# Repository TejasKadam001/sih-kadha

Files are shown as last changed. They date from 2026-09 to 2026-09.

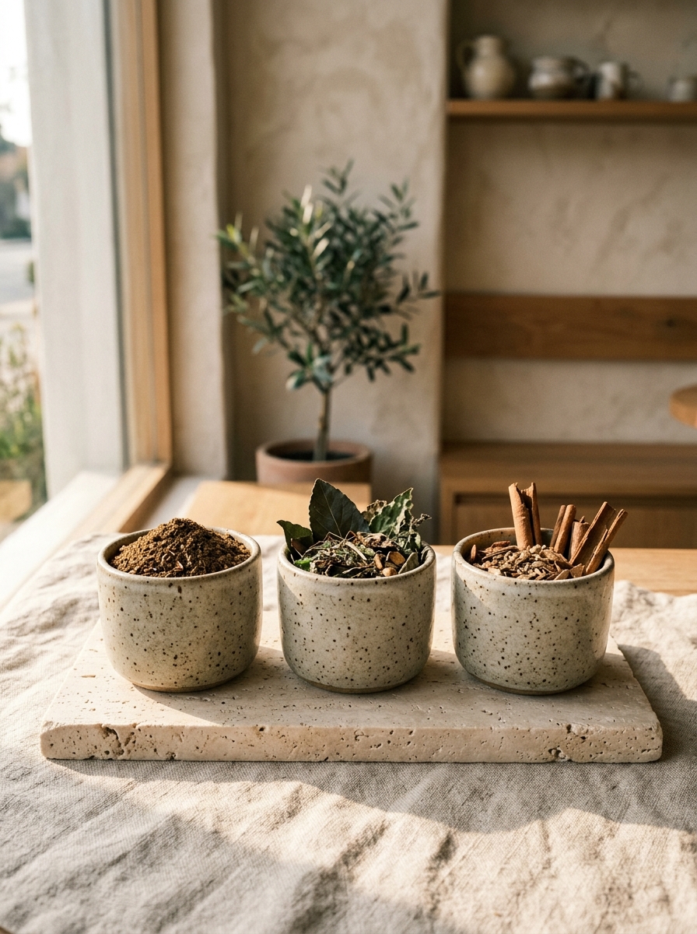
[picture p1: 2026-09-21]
website/assets/pods_tray.jpg

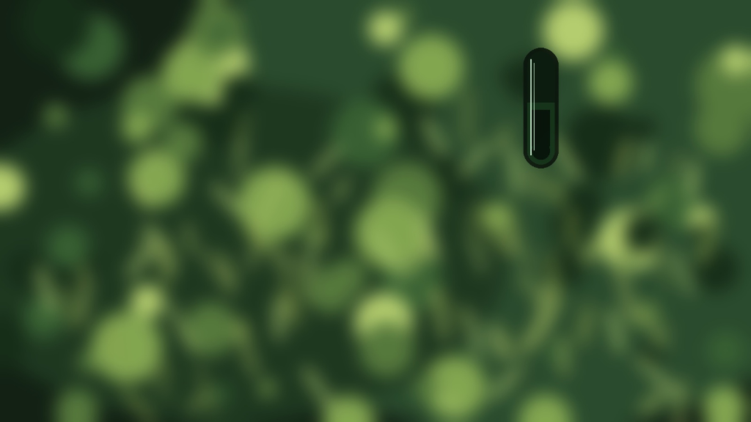
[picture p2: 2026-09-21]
app/assets/science_macro.jpg

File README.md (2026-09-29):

# iKwath: Smart Pod-Based Ayurvedic Decoction Appliance

**SIH26048: iKwath, a pod-based smart Kwatha (Kadha) maker that prepares a fresh, AFI/API-standardized decoction from coarse powder (yavakuta churna) on demand, in the shortest practical time, without altering the decoction's quality or yield**
Ministry of Ayush / All India Institute of Ayurveda (AIIA) | Smart India Hackathon 2026
**Team:** MACH 2
**Design philosophy:** Classical Fidelity | Hardware-Enforced Safety | Measured Endpoints, Not Timers | Honest Project Status








---

## 1. Problem Statement Context (SIH26048)

Kwatha (also Kashaya or Kadha) is the primary aqueous decoction in Ayurveda. Coarse herbal powder (yavakuta churna) is boiled in a specified multiple of water and reduced, classically to one quarter of the volume, then filtered immediately.

The difficulty is that a classical Kwatha has no preservatives and stays therapeutically useful for only a few hours. Making it properly means 45 to 60 minutes of monitored simmering, so patients and OPD clinics often switch to bottled, industrially preserved syrups that suffer thermal degradation or inconsistent yield.

* **Long manual process:** open-pot evaporation needs constant attention for close to an hour.
* **Temperature ceiling:** classical practice prescribes gentle heat (Manda Agni). At or above 100 C volatile terpenes and thermolabile glycosides degrade.
* **Standardization gap:** hand preparation varies in water ratio, reduction and filtration, so dose consistency is poor.
* **No traceability:** there is no record of what was brewed, from which batch, at what concentration.

---

## 2. Integrated Solution Overview

**iKwath** is a countertop, single-dose extraction appliance built around five ideas:

1. **Pod-based dosing:** a single-use pod holds 25 to 35 g of certified coarse powder and doubles as the filter (150 to 250 micron mesh). An NTAG213 NFC tag on the rim carries the formulation profile.
2. **Vacuum-assisted evaporation:** the sealed SS304 chamber runs at 0.5 to 0.6 atm so water boils at about 82 to 86 C. The liquid boils vigorously while staying inside the 85 to 90 C envelope.
3. **Measured endpoint:** a load cell tracks the mass of the chamber and ends the boil when 300 g (+/- 2 g) has evaporated, an exact 4:1 reduction of 400 mL. The endpoint is a measurement, not a timer.
4. **Three independent hardware safety layers:** fuse, lid interlock and bimetallic thermal cutoff, all working with the firmware switched off.
5. **Companion app and cloud model:** live brew dashboard, pod profile catalogue, dose log and clinic fleet view (see the status note in section 8).

> Scientific and engineering classification: iKwath is a prototype design for a standardized decoction appliance. It is not a certified medical device, and this repository does not contain laboratory validation of extract quality. See section 10 for what is and is not built.

---

## 3. Extraction Physics

The Ayurvedic Formulary of India (AFI) and Ayurvedic Pharmacopoeia of India (API) set water ratio by herb hardness:

| Herb class | Parts | Water ratio (w/w) | Reduction | Concentration |
|---|---|---|---|---|
| Soft (Mridu): leaves, flowers | 16 | 16 | to 1/4 | about 4x |
| Medium (Madhyama): bark, stems | 8 | 8 | to 1/4 | about 2x |
| Hard (Kathina): roots, heartwood | 4 | 4 | to 1/4 | about 1x |

The working profile is 400 mL of water reduced to a 100 mL dose.

Cycle time falls from 45 to 60 minutes to 9 to 12 minutes without raising liquid temperature, using four levers:

```mermaid
graph TD
    A[Classical bottleneck] --> B[Open pot at 98-100 C]
    B --> C[Slow evaporation: 45-60 min]
    B --> D[Thermal loss of volatile actives]

    E[iKwath approach] --> F[Sealed chamber at 0.5-0.6 atm]
    F --> G[Boils at 82-86 C, Manda Agni preserved]
    E --> H[Wide shallow pan: about 3x surface area]
    E --> I[Recirculation over the pod bed]
    E --> J[Forced vapor exhaust]

    G --> K[Active cycle target: 9-12 min]
    H --> K
    I --> K
    J --> K
```

Particle size follows PCIM&H specification AFI/2020/KC/1.0: 100 percent through IS sieve 22 (710 micron) and not more than 10 percent through sieve 44 (355 micron). Details: [docs/pod-and-extraction.md](docs/pod-and-extraction.md).

---

## 4. Machine Working Principle

```mermaid
stateDiagram-v2
    [*] --> Idle: Powered on
    Idle --> PodDetect: Pod inserted, lid latched
    PodDetect --> WaterFill: NFC profile validated
    WaterFill --> PreSoak: 400 mL metered by load cell
    PreSoak --> ActiveBoil: 180 s soak finished

    state ActiveBoil {
        [*] --> PressureRamp: Vacuum pump on
        PressureRamp --> PIDHold: 0.5-0.6 atm reached
        PIDHold --> PIDHold: Temperature held 85-88 C
        PIDHold --> MassCheck: Recirculation running
        MassCheck --> [*]: 300 g evaporated
    }

    ActiveBoil --> Dispense: Vent chamber, run dispense pump
    Dispense --> Eject: about 100 mL delivered
    Eject --> Idle: Pod dropped to bin
```

Eight steps: interlocked pod loading, metered water intake, pre-soak, controlled vacuum boil, recirculation with vapor stripping, mass-reduction endpoint, filtered dispense at 55 to 60 C, automatic pod ejection. Step-by-step detail: [docs/control-sequence.md](docs/control-sequence.md).

---

## 5. Repository Layout

```
SIH/
├── README.md                      Main specification and status
├── INSTALL.md                     How to open, run and rebuild each part
├── CHANGELOG.md                   Versioned release notes
├── PUSH_LOG.md                    What each push to the repository did
├── SIH26048_PROJECT_REPORT.md     Full technical submission report
├── ps_shortlist.md                Problem-statement shortlist and selection notes
├── app/                           Product landing site (single page, with media assets)
│   ├── index.html
│   ├── styles.css
│   ├── assets/                    Product, pod and lifestyle imagery, hero video
│   └── _assets_backup/            Unused media with a restore script
├── website/                       Interactive brew-simulator web app (HTML, CSS, JS)
│   ├── index.html
│   ├── styles.css
│   ├── app.js                     Screen state machine, extraction simulator, greetings
│   ├── manifest.json
│   └── assets/
├── pcb/                           Committed KiCad project (control and power circuitry)
│   ├── ikwath.kicad_sch
│   ├── ikwath.kicad_pcb
│   └── ikwath.kicad_pro
├── ino/                           ESP32 firmware (Arduino sketch)
│   └── ikwath_firmware/
│       ├── ikwath_firmware.ino    State machine, sensors, safety checks, serial and optional HTTP
│       ├── pins.h  config.h       Pin map and tunable settings
│       ├── pid.h  hx711_lite.h    Heater PID and load-cell reader
│       └── profile.h              Pod tag payload format
├── models/                        Process model notebook: vacuum boiling, energy budget, endpoint noise, pod tag
│   └── ikwath_process_model.ipynb
├── docs/                          Engineering documentation derived from this repository
│   ├── pod-and-extraction.md
│   ├── control-sequence.md
│   ├── pinout-and-buses.md
│   ├── safety-system.md
│   ├── pcb-status.md
│   ├── bom.md
│   ├── app-and-cloud.md
│   ├── limitations.md
│   ├── judge-qna.md
│   └── README.md
├── blehpcb/                       Local PCB generation work (gitignored)
│   ├── BOM.csv
│   ├── generate_final_kicad8.py
│   ├── ikwath-control-board/  ikwath-power-board/
│   ├── *-drc.rpt  *-erc.rpt       KiCad rule-check reports
│   └── pcbreal/                   Scripted placement, routing and stackup iterations
└── blehread/                      Local research dossiers (gitignored)
    ├── research.md  structure.md  pcb.md  app_and_website.md  names.md  open.md
```

The two gitignored folders are working material that lives only on the author's machine; see [PUSH_LOG.md](PUSH_LOG.md) for what is actually pushed.

---

## 6. Dual-PCB Hardware Architecture

The electronics are split into two boards so that sensitive analog measurement is isolated from inductive relay switching.

```mermaid
flowchart LR
    subgraph PB["Power Board"]
        AC["220V AC"] --> PS1["12V 5A AC-DC supply"]
        PS1 --> F1["5A DC fuse"]
        F1 --> V12["12V bus"]
        V12 --> BUCK["LM2596 buck to 5V"]
        V12 --> RLY["Relays 1-7: heater, vacuum pump, recirculation pump, dispense pump, inlet valve, lid lock, exhaust fan"]
    end

    subgraph CB["Control Board"]
        MCU["ESP32 DevKit V1"]
        MCU --> DS["DS18B20 liquid temperature"]
        MCU --> HX["HX711 + load cell"]
        MCU --> NFC["MFRC522 NFC reader"]
        MCU --> I2C["I2C bus"]
        I2C --> OLED["SSD1306 OLED"]
        I2C --> BMP["BMP280 pressure"]
        I2C --> PCF["PCF8574 x2: relays, LEDs"]
        MCU --> TDS["Analog TDS sensor"]
        MCU --> SW["Limit switches: lid, boil-over, level"]
        MCU --> SRV["SG90 pod ejector"]
    end

    BUCK -->|5V| MCU
    PB <-->|"Ribbon: power, I2C, PID, signals"| CB
```

| Board | Target size | Notes |
|---|---|---|
| Control | 70 x 60 mm in the specification (generated variants are larger, see [docs/pcb-status.md](docs/pcb-status.md)) | 2-layer, dedicated analog ground zone, 4x M3 |
| Power | 80 x 70 mm in the specification | 2-layer, heavy power traces, opto-isolated relay drive, 4x M3 |

Pin map and I2C addresses: [docs/pinout-and-buses.md](docs/pinout-and-buses.md).

---

## 7. Three-Tier Hardware Safety System

These layers act independently of firmware:

1. **Bimetallic thermal cutoff (95 to 100 C)**, in contact with the boiler wall and in series between Relay 1 and the heater. If the chamber overheats for any reason, including a welded relay, it opens the circuit.
2. **Mechanical lid interlock**, wired in series with the heater's 12 V feed. Opening the lid cuts heater power in hardware.
3. **5 A fast-acting fuse** on the 12 V rail against short circuits and pump stall.

The firmware in `ino/` adds supervisory checks on top (boil-over sensor, water level, enclosure NTC, over-temperature, timeouts); it is a first draft that has not yet run on the appliance (section 10). Details: [docs/safety-system.md](docs/safety-system.md).

---

## 8. Companion Applications

Two web front ends are in the repository. Both run with no build step and no dependencies.

| Folder | What it is |
|---|---|
| `website/` | Interactive mobile-style app: logo intro, login, time-based greeting, pod dropdown (Triphala, Ayush, Dashamoola), five-stage extraction simulator with live countdown, temperature dial, 400 to 100 mL gauge and a PID curve pinned to the 85 to 90 C band, notification bell, pod scanner viewfinder, profile view, Android frame toggle |
| `app/` | Single-page product site: appliance, pods, app, formulations, science and standards sections, sign-in and sign-up modals, product photography and hero video |

**Status:** the extraction screen is a simulator driven by `website/app.js`. It does not connect to a device. The BLE provisioning, local WebSocket, MQTT telemetry and cloud database described in [docs/app-and-cloud.md](docs/app-and-cloud.md) are the intended architecture, not running code.

---

## 9. Bill of Materials

`blehpcb/BOM.csv` lists 46 line items (ESP32, sensors, NFC reader, display, expanders, 7 relays, pumps, valves, heater, servo, fan, safety parts, passives and connectors). The file's own total row, and the sum of its cost column, is **INR 4,588** (about US$55), reading each figure as a line total. If those were unit prices the bill would be INR 8,335, so spot-check a few lines against supplier listings before quoting a cost. Full table and notes: [docs/bom.md](docs/bom.md).

---

## 10. Project Status: Built Versus Designed

| Area | Status |
|---|---|
| Problem analysis, extraction physics, pod design | Written (`blehread/research.md`, `docs/pod-and-extraction.md`) |
| Pin-by-pin hardware specification | Written (`blehread/pcb.md`, `docs/pinout-and-buses.md`) |
| KiCad schematic and PCB | Present in several iterations; `pcb/` is the committed one. Rule-check results vary by iteration, and copper routing is incomplete in some (see [docs/pcb-status.md](docs/pcb-status.md)) |
| Web front ends | Built and runnable; extraction is simulated |
| ESP32 firmware | Written (`ino/`): full cycle, safety checks, serial and optional HTTP interface. Not yet compiled here or run on hardware |
| Physical prototype and lab validation | **Not done** (no measured extract quality, no measured cycle time) |
| Mobile app, cloud backend, MQTT | **Design only** |

The 9 to 12 minute cycle, the 85 to 90 C envelope and the 300 g endpoint are design targets derived from the physics, not measured results. An energy balance in `models/ikwath_process_model.ipynb` shows that the cycle time is set by heater power: the 50 W element in the current bill of materials is far too small for a 12 minute cycle, so the heater is an open design decision. [docs/limitations.md](docs/limitations.md) lists what is needed to turn each into a measured claim.

---

## 11. Documentation Map

| Document | Contents |
|---|---|
| [SIH26048_PROJECT_REPORT.md](SIH26048_PROJECT_REPORT.md) | Full technical submission report |
| [INSTALL.md](INSTALL.md) | Run the web apps, open the PCB, regenerate boards |
| [CHANGELOG.md](CHANGELOG.md) | Versioned release notes |
| [PUSH_LOG.md](PUSH_LOG.md) | What each push did |
| [ino/README.md](ino/README.md) | Firmware structure, cycle, safety checks, serial commands |
| [docs/](docs/README.md) | Engineering documentation set |

---

## 12. Authoritative Standards and Citations

* PCIM&H, *AFI/2020/KC/1.0: Formulary Specification of AYUSH Kvatha Churna*, Ghaziabad.
* PCIM&H, *API-2/2020/KC/1.0: Pharmacopoeial Monograph of AYUSH Kvatha Churna*, Ministry of Ayush.
* *The Ayurvedic Pharmacopoeia of India*, Parts I and II, First Edition, Ministry of Health and Family Welfare / Ministry of Ayush.
* All India Institute of Ayurveda (AIIA): guidance on quality control, good dispensing practice and clinical standardization of extemporaneous decoctions.

---

*iKwath, Smart India Hackathon 2026, Ministry of Ayush / AIIA*
*Team: MACH 2*

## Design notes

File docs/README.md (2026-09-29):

# iKwath documentation

Engineering notes derived from what is in this repository. Start with the top-level [README](../README.md); use these pages for detail.

| Document | Read it for |
|---|---|
| [pod-and-extraction.md](pod-and-extraction.md) | Pharmacopoeial ratios, particle size, vacuum boiling physics, pod and NFC design |
| [control-sequence.md](control-sequence.md) | The eight-step cycle, endpoint by mass, what firmware still has to settle |
| [pinout-and-buses.md](pinout-and-buses.md) | ESP32 pins, I2C addresses, relay assignment |
| [safety-system.md](safety-system.md) | Three hardware layers plus specified firmware supervision |
| [pcb-status.md](pcb-status.md) | Which board files exist, reported DRC and ERC results, deviations |
| [bom.md](bom.md) | Full parts table generated from `blehpcb/BOM.csv` and how to read the total |
| [app-and-cloud.md](app-and-cloud.md) | What the two web apps do today versus the intended app and cloud design |
| [../ino/README.md](../ino/README.md) | The ESP32 firmware: cycle, safety checks, serial commands |
| [../models/README.md](../models/README.md) | Process model notebook and what it shows |
| [limitations.md](limitations.md) | Twelve gaps and what closes each |
| [judge-qna.md](judge-qna.md) | Likely questions with straight answers |

Project-level documents: [SIH26048_PROJECT_REPORT.md](../SIH26048_PROJECT_REPORT.md), [INSTALL.md](../INSTALL.md), [CHANGELOG.md](../CHANGELOG.md), [PUSH_LOG.md](../PUSH_LOG.md).

Longer research notes (`blehread/`) and PCB generation work (`blehpcb/`) are gitignored and live only on the author's machine.

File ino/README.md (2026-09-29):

# ino: ESP32 firmware

Arduino sketch for the iKwath control board. It implements the brew cycle from [docs/control-sequence.md](../docs/control-sequence.md) on the pin map in [docs/pinout-and-buses.md](../docs/pinout-and-buses.md).

**Status:** written from the specification. It has not been compiled on this project's toolchain and has not been run on the appliance. Treat it as a first draft for bench bring-up, and measure every `CALIBRATE` value in `config.h` before any powered test.

## Layout

```
ino/
└── ikwath_firmware/
    ├── ikwath_firmware.ino   State machine, sensors, safety checks, serial and optional HTTP interface
    ├── pins.h                GPIO numbers, I2C addresses, expander bit assignments
    ├── config.h              Thresholds, PID gains, calibration, behaviour switches
    ├── pid.h                 PID with output clamp and anti-windup
    ├── hx711_lite.h          Small HX711 reader (no external library)
    └── profile.h             Pod tag payload format and validation
```

## Cycle

```
IDLE -> READY -> FILL -> SOAK -> BOIL -> VENT -> DISPENSE -> EJECT -> DONE
                 any powered state -> FAULT
```

| State | What happens | Exit |
|---|---|---|
| IDLE | Waits for a pod tag | tag read |
| READY | Profile loaded (from tag, else defaults); waits for start | `s` command, or `AUTO_START` |
| FILL | Locks lid, opens inlet valve | mass gain reaches the profile water volume |
| SOAK | Gentle warm-up while the herb hydrates | profile pre-soak time |
| BOIL | Heater PID at the setpoint, vacuum pump with hysteresis, recirculation and exhaust on | evaporated mass reaches the target (within tolerance) |
| VENT | Waits for the chamber to return to ambient (no vent valve is fitted) | pressure back near ambient |
| DISPENSE | Dispense pump | mass drop reaches the dose volume |
| EJECT | Unlocks lid, servo trips the pod catch, beeps | done |
| FAULT | All outputs off | `r` after the cause has cleared |

The endpoint is mass-based: `evaporated = mass at boil start - current mass`.

## Safety checks in software

These add to, and never replace, the hardware layers (lid interlock, bimetallic cutoff, fuse):

* lid opened during a powered state
* liquid probe missing or out of range
* liquid temperature at or above 92 C
* enclosure temperature at or above 60 C
* load cell not responding
* boil-over sensor triggered while heating
* fill, boil, vent, dispense and total-cycle timeouts
* start refused when the lid is open, no pod is read, the tank is empty or sensors are not ready

All outputs are driven to their safe state at the very start of `setup()`, before peripherals initialise.

## Pod tag format

16 bytes at NTAG213 page 4: `'I' 'K'`, version, water-ratio class, pre-soak seconds, target evaporated grams, setpoint, minimum TDS, water mL, dose mL, reserved, XOR checksum. Invalid or out-of-envelope tags fall back to the default profile in `config.h`. Full layout is in `profile.h`.

## Serial interface (115200 baud)

| Command | Action |
|---|---|
| `s` | start the cycle |
| `x` | abort, all outputs off |
| `r` | clear a fault |
| `t` | tare the load cell |
| `cal <grams>` | calibrate with a known mass on the scale; saved to flash |

Telemetry is one JSON line per second (state, temperature, pressure, mass, evaporated grams, TDS, heater percent, flags). With `ENABLE_WIFI 1` the sketch also serves `/status`, `/start` and `/stop`, which is the hook for connecting the web app later.

## Building

Board: ESP32 Dev Module (ESP32 DevKit V1). Libraries (Library Manager): Adafruit SSD1306, Adafruit GFX, Adafruit BMP280, OneWire, DallasTemperature, ESP32Servo, and MFRC522. The HX711 reader is included in the sketch folder, and the PCF8574 expanders are driven directly over I2C.

## Known gaps

* Not yet compiled or run; expect first-build fixes.
* Load-cell readings under vacuum and hose forces need characterising (see docs/limitations.md).
* No vent valve in the current design, so VENT relies on a passive bleed.
* Relay and LED polarity are set by `RELAY_ACTIVE_LOW` and `LED_ACTIVE_LOW`; confirm against the real modules.
* The pod-catch servo angle and the NTC divider orientation are assumptions to verify on the bench.

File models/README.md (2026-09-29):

# models

`ikwath_process_model.ipynb` is a Python notebook that checks the iKwath design targets against basic physics. It needs only NumPy and Matplotlib. All figures are calculated from design parameters, not measured on a machine.

| Section | Question it answers |
|---|---|
| Vacuum boiling point | At the chamber pressures in the design, what temperature does water boil at? |
| Energy budget | How much heater power does a given cycle time need? |
| Heat-up and reduction simulation | How does temperature and evaporated mass evolve for different heater sizes? |
| Endpoint detection | How much does load-cell noise shift the mass-based stopping point? |
| Pod tag payload | Encode, decode and validate the 16-byte tag profile used by the firmware |

## What it currently shows

* Vacuum at 50 to 60 kPa puts boiling at roughly 81 to 86 C, under the 90 C ceiling.
* Latent heat is about 87 percent of the energy needed. The 50 W heater in the bill of materials needs hours for the full reduction; a 12 minute cycle needs on the order of 1.4 kW into the water. This is an open design decision (see `docs/limitations.md`).
* A short moving average keeps the endpoint within the 2 g tolerance for load-cell noise up to a couple of grams rms; measure the real noise floor on the bench.

## Run

```bash
cd models
jupyter notebook ikwath_process_model.ipynb
```

Every assumption sits in the first code cell (heater power, efficiency, temperatures, masses) so it can be replaced with bench data.

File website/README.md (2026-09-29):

# iKwath · HERB — Smart Pod-Based Ayurvedic Decoction Maker

> **Ministry of Ayush / All India Institute of Ayurveda (AIIA) · SIH 2026 Problem Statement 26048**\
> Frontend web application designed with a quiet luxury cafe aesthetic, tailored for Android mobile viewports and presentations.

***

## Overview

**iKwath · HERB** is a smart appliance and mobile control surface that prepares fresh, standardized Ayurvedic decoctions (*Kwatha / Kadha*) in 12 minutes—strictly constrained to the classical **85–90°C Manda Agni (gentle heat)** temperature band using reduced-pressure vacuum boiling.

***

## Features

* **Pure Logo Intro with Blur Transition**: Starts with the centered brand logo on a natural sage stone background (`#BBC0A9`), gently breathing, and smoothly blurs out into the login screen.

* **Minimalist Login Page**: Borderless, breathable inputs with subtle hairline accents; includes Email, Password with eye toggle, and "Enter with Google".

* **Dynamic Time-Based Greeting**:

  * `Good morning` (5 AM – 12 PM) — *"A warm cup of kadha brings gentle balance to start your day."*

  * `Good afternoon` (12 PM – 5 PM) — *"Take a mindful pause with a refreshing, revitalizing cup of kadha."*

  * `Good evening` (5 PM – 9 PM) — *"Unwind your senses with a soothing, warm herbal decoction."*

  * `Good night` (9 PM – 5 AM) — *"Rest deeply as gentle healing herbs restore you overnight."*

* **Split Hero Card**: Clean typography on the left and an aesthetic beverage pod image framed in a white rounded container on the right.

* **In-App Active Pod Dropdown**: Clicking the active Kadha card smoothly expands an interactive accordion to select among certified blends (*Triphala Kadha*, *Ayush Kadha*, *Dashamoola Kadha*).

* **Interactive Extraction Engine**:

  * 5-stage progress: `Soak` → `85°C Boil` → `Reduce 4:1` → `Filter` → `Dispense`

  * Live countdown timer (e.g. `12:00 left`)

  * Real-time temperature dial and volume reduction gauge (400 mL → 100 mL)

  * Interactive Canvas PID temperature curve pinned to the 85–90°C safe zone

* **Notification Bell with Red Dot**: Lights up with an animated red dot when dispensing finishes.

* **Pod Camera Scanner**: Dedicated camera icon opening a viewfinder simulator to scan pod QR codes/NFC tags.

* **User Profile**: Profile section for **Tejas Kadam** (`tejaskadam@gmail.com`, Male) with paired device diagnostics.

* **Android Mockup Chassis**: Built-in toggle to view inside an authentic Android frame for capturing pitch deck screenshots.

***

## How to Run the Project

This project is built using pure **HTML5, CSS3, and modern JavaScript** with **zero external dependencies** or build steps required.

### Method 1: Using Python (Recommended)

Run the built-in HTTP server from the `website` directory:

```bash
# 1. Navigate to the website directory
cd /Users/tanmaykadam/Desktop/dex/CS/Hackathon/SIH/website

# 2. Start the local server
python3 -m http.server 8080
```

Open your browser and navigate to:

```
http://localhost:8080
```

***

### Method 2: Using Node.js / npx serve

If you have Node.js installed:

```bash
cd /Users/tanmaykadam/Desktop/dex/CS/Hackathon/SIH/website
npx serve .
```

***

### Method 3: Direct File Opening (macOS)

You can open `index.html` directly in your default browser:

```bash
open /Users/tanmaykadam/Desktop/dex/CS/Hackathon/SIH/website/index.html
```

***

## Project Structure

```
website/
├── index.html         # Main application markup (all screens, tabs, modals)
├── styles.css         # Minimalist cafe design system & fluid transitions
├── app.js             # State machine, kinetics simulator, dynamic greetings
├── README.md          # Project documentation & run guide
├── logo.png           # Original HERB brand identity
├── research.md        # Technical research dossier for SIH PS 26048
├── app_and_website.md # Technical specification & system requirements
└── assets/
    ├── hero_drink.jpg         # High-res iced matcha/herbal beverage
    ├── pods_tray.jpg          # Travertine tray with herbal Kadha powders
    ├── warm_cup.jpg           # Steaming golden Ayurvedic decoction in ceramic cup
    ├── logo_transparent.png  # Transparent brand logo for light theme
    └── logo_white.png        # Transparent white brand logo
```

***

## Presentation Tips for Evaluators

1. **Android Screenshot Mode**: Use the **"Android Frame"** button on the top evaluator dock to switch between the framed phone chassis and full-screen view.
2. **Replay Intro**: Click **"Replay Intro"** on the floating dock to showcase the smooth logo blur entrance.
3. **Simulate Live Brew**: Click **"Begin Cycle"** to demonstrate real-time temperature regulation locked within the 85–90°C pharmacopoeial ceiling.
4. **Website Showcase**: Click **"Website"** in the top dock to toggle the public landing page explaining the 7-stage extraction kinetics.

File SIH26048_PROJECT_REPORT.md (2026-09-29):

# iKwath: Technical Project Report
## Smart Pod-Based Ayurvedic Decoction Appliance (Kwatha / Kadha Maker)

```
========================================================================================
PROJECT IDENTITY AND METADATA
========================================================================================
Hackathon:            Smart India Hackathon 2026 (SIH 2026)
Problem Statement ID: SIH26048
Organization:         Ministry of Ayush / All India Institute of Ayurveda (AIIA)
Category:             Hardware / MedTech / BioTech / HealthTech
Team:                 MACH 2
Report version:       0.4.0
Date:                 September 2026
Repository state:     3 commits on 2026-09-21 plus a documentation pass
What is built:        Specification, KiCad PCB iterations, two runnable web front ends
Firmware:             Drafted in ino/, not yet run on hardware
What is not built:    Physical prototype, laboratory validation
========================================================================================
```

## Table of Contents
1. Executive Summary
2. Problem Statement Analysis
3. Extraction Physics and Design Approach
4. Pod Architecture
5. Machine Fluidics and Working Principle
6. Electronics Architecture
7. Safety Design
8. Process Control and Endpoint Detection
9. Applications and IoT Design
10. Verification and Current Status
11. Bill of Materials and Economics
12. Limitations and Roadmap
13. Conclusion

---

## 1. Executive Summary

Kwatha is the principal aqueous decoction of Ayurveda: coarse herbal powder boiled in a multiple of water, reduced classically to one quarter and filtered at once. It has no preservatives and is therapeutically useful for only a few hours, yet preparing it properly takes 45 to 60 minutes of attended simmering. People therefore turn to bottled syrups that degrade or vary in strength.

**iKwath** is a countertop, single-dose appliance that aims to prepare a fresh, standardised Kwatha from a sealed pod in about 9 to 12 minutes. It relies on vacuum-assisted boiling (0.5 to 0.6 atm, boiling near 82 to 86 C) so the liquid stays inside the 85 to 90 C classical envelope, a wide shallow pan with recirculation and vapor exhaust for speed, an NFC-coded pod that carries the brew profile, and a load-cell endpoint that ends the boil after exactly 300 g of evaporation from 400 g of water.

The design is split across two PCBs (control and power), protected by three hardware safety layers that work without firmware, and paired with two web front ends that present the product and simulate the brew.

This report separates what is designed from what is built. The specification, the PCB files, the firmware draft and the web apps exist. A working prototype and any measurement of cycle time or extract quality do not yet exist, and the firmware in `ino/` is a first draft that has not yet run on the appliance.

---

## 2. Problem Statement Analysis

| Issue | Detail |
|---|---|
| Short shelf life | Classical Kwatha lasts hours, not days |
| Long preparation | 45 to 60 minutes of monitored simmering |
| Heat sensitivity | Above 100 C volatile terpenes and thermolabile glycosides degrade |
| Variability | Manual ratio, reduction and filtration differ from cook to cook |
| No records | No batch, concentration or dose traceability |

The problem statement asks for a pod-based smart maker that produces an AFI/API-standardised decoction from coarse powder on demand, quickly, without altering quality or yield.

---

## 3. Extraction Physics and Design Approach

### 3.1 Pharmacopoeial parameters
| Herb class | Water ratio (w/w) | Reduction |
|---|---|---|
| Soft (leaves, flowers) | 16 | to 1/4 |
| Medium (bark, stems) | 8 | to 1/4 |
| Hard (roots, heartwood) | 4 | to 1/4 |

Working profile: 400 mL reduced to 100 mL.

### 3.2 Particle size
PCIM&H AFI/2020/KC/1.0: all material through IS sieve 22 (710 micron) and no more than 10 percent through IS sieve 44 (355 micron), so the bed stays permeable and fines do not clog the mesh.

### 3.3 Speed without heat
| Lever | Effect |
|---|---|
| Reduced pressure, 0.50 to 0.60 atm | boiling point about 81 to 86 C, vigorous boil inside the envelope |
| Wide shallow pan, 150 to 200 cm2 | about three times the evaporating surface of a tall pot |
| Vapor exhaust | removes saturated air above the liquid |
| Recirculation over the pod bed | removes diffusion boundary layers and hot spots |

The 9 to 12 minute cycle is the design target implied by these levers. It has not been measured.

---

## 4. Pod Architecture

* Charge: 25 to 35 g of coarse powder.
* Filter: integrated mesh, 150 to 250 micron.
* Shell: food-grade polypropylene or pressed cellulose, BPA-free, rated to 100 C in water.
* Identity: NTAG213 NFC tag (13.56 MHz) read by an MFRC522.
* Tag payload (design): formulation ID, water ratio class, pre-soak time (180 to 300 s), target evaporated mass, temperature setpoint (85 to 88 C), target extract density.

Detail: `docs/pod-and-extraction.md`.

---

## 5. Machine Fluidics and Working Principle

```mermaid
stateDiagram-v2
    [*] --> Idle
    Idle --> PodDetect: pod inserted, lid latched
    PodDetect --> WaterFill: NFC profile valid
    WaterFill --> PreSoak: 400 mL metered
    PreSoak --> ActiveBoil: soak elapsed
    ActiveBoil --> Dispense: 300 g evaporated
    Dispense --> Eject: about 100 mL delivered
    Eject --> Idle
```

Eight steps: interlocked loading, metered water intake, pre-soak, vacuum boil under PID, recirculation with vapor stripping, mass-based endpoint, filtered dispense at 55 to 60 C, and servo pod ejection. Seven relays drive the heater, vacuum pump, recirculation pump, dispense pump, inlet valve, lid lock and exhaust fan. Detail: `docs/control-sequence.md`.

---

## 6. Electronics Architecture

Two boards isolate measurement from switching.

| Board | Function | Contents |
|---|---|---|
| Control | Sensing, logic, display | ESP32 DevKit V1; DS18B20; HX711 with load cell; MFRC522; BMP280; analog TDS sensor; 10 kOhm NTC; SSD1306 OLED; two PCF8574 expanders; three limit switches; four status LEDs; buzzer; SG90 servo |
| Power | Mains conversion and actuation | 12 V 5 A AC-DC supply; 5 A fuse; LM2596 buck to 5 V; seven opto-isolated relays; heater safety wiring |

Pin map, I2C addresses (0x3C OLED, 0x76 BMP280, 0x20 and 0x21 expanders) and relay table: `docs/pinout-and-buses.md`.

---

## 7. Safety Design

Three layers act independently of firmware: a bimetallic cutoff (95 to 100 C) on the boiler wall in series with the heater; a lid interlock in series with the heater feed; and a 5 A fuse on the 12 V rail. The firmware is specified to add boil-over, water-level, enclosure-temperature and liquid-temperature supervision. Detail and gaps: `docs/safety-system.md`. No electrical or medical-device certification has been attempted, and no independent mains-side review has been done.

---

## 8. Process Control and Endpoint Detection

* Heater temperature is held by PID at the pod-profile setpoint (85 to 88 C).
* Chamber pressure is monitored by the BMP280 against the 50 to 60 kPa target.
* The endpoint is delta_m = m0 - m(t) = 300 g (+/- 2 g), which represents the 4:1 reduction of 400 mL, measured by the load cell.
* A TDS sensor logs conductivity against the formulation's baseline curve as a consistency proxy. It does not replace laboratory fingerprinting.

Open engineering questions: load-cell behaviour under vacuum, vacuum control law and vent timing, and failure handling (dry boil, lid opened mid-cycle, unreadable tag).

---

## 9. Applications and IoT Design

### 9.1 Built
* `website/`: interactive app with logo intro, greeting, pod selection (Triphala, Ayush, Dashamoola), five-stage extraction simulator, temperature curve pinned to the 85 to 90 C band, notification bell, pod scanner viewfinder, profile screen, Android frame toggle.
* `app/`: one-page product site with product imagery and a hero video.
Both are dependency-free HTML, CSS and JavaScript, and neither connects to hardware.

### 9.2 Designed
BLE provisioning, a local WebSocket for offline control, MQTT telemetry for clinic fleets, a formulation catalogue mapped to NFC tag IDs, and a dose compliance log. Detail: `docs/app-and-cloud.md`.

---

## 10. Verification and Current Status

| Item | Status | Evidence |
|---|---|---|
| Specification and physics | Written | README, `docs/`, research notes |
| Web apps | Run in a browser | `website/`, `app/` |
| KiCad electrical rules | Run on the generated iterations; no electrical-rule errors reported | `blehpcb/*-erc.rpt` |
| KiCad design rules | Run on several iterations; final clean-up before fabrication is pending | `docs/pcb-status.md` |
| Committed board (`pcb/`) | routed copper present; no stored rule report | `pcb/ikwath.kicad_pcb` |
| Firmware | Drafted (`ino/`); not yet compiled here or run on hardware | `ino/ikwath_firmware/` |
| Prototype and lab tests | not done | none |

Detail on the board iterations: `docs/pcb-status.md`.

---

## 11. Bill of Materials and Economics

The bill (`blehpcb/BOM.csv`, 46 numbered items) totals **INR 4,588** (about US$55) by its own total row, reading the cost column as line totals; INR 8,335 if those were unit prices. Excluded: enclosure, SS304 chamber, tubing, fittings, pod tooling, PCB fabrication and food-grade upgrades of contact parts. Full table: `docs/bom.md`.

No unit-economics analysis (pod cost, price, margin) exists in the repository.

---

## 12. Limitations and Roadmap

### 12.1 Limitations
Firmware untested; no prototype; no extract-quality data; simulated app; design-only cloud; PCB not finalised; prototype-grade BOM; vacuum-and-load-cell interaction untested; mains side unreviewed; repository hygiene items open. The full list with remedies is in `docs/limitations.md`.

### 12.2 Roadmap
1. Choose the final PCB variant, fix footprints, complete routing, store DRC and ERC results.
2. Compile, bench-test and calibrate the firmware in `ino/` (eight-step cycle and safety supervision).
3. Build the chamber and log full cycles of temperature, pressure and mass.
4. Send extracts to a certified lab and compare with hand-prepared Kwatha.
5. Connect the web app to the device over WebSocket, then add BLE provisioning and MQTT.
6. Source certified formulation profiles and food-grade contact parts.

---

## 13. Conclusion

iKwath addresses a real gap: fresh, correctly reduced Kwatha in minutes rather than an hour, without exceeding classical gentle heat. The approach (vacuum boiling, NFC-coded pods, mass-based endpoint, hardware-first safety) is grounded in the pharmacopoeial parameters and is documented in detail. What remains is to turn design targets into measurements: firmware, a working prototype and laboratory results.

*iKwath, Smart India Hackathon 2026, Ministry of Ayush / AIIA. Team MACH 2.*

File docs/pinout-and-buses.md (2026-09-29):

# Pinout and buses

Specified for an ESP32 DevKit V1 (38 pin). Source: the hardware specification in the README and `blehread/pcb.md`.

## ESP32 pin map

| Pin | Function | Notes |
|---|---|---|
| GPIO4 | DS18B20 liquid temperature | 1-Wire, 4.7 kOhm pull-up to 3.3 V |
| GPIO16 | HX711 DT | data |
| GPIO17 | HX711 SCK | clock |
| GPIO5 | MFRC522 SS | SPI chip select |
| GPIO18 | MFRC522 SCK | SPI clock |
| GPIO19 | MFRC522 MISO | |
| GPIO23 | MFRC522 MOSI | |
| GPIO27 | MFRC522 RST | reset |
| GPIO21 | I2C SDA | 4.7 kOhm pull-up |
| GPIO22 | I2C SCL | 4.7 kOhm pull-up |
| GPIO34 | Analog TDS sensor | ADC input (input-only pin) |
| GPIO32 | 10 kOhm NTC thermistor | enclosure temperature divider |
| GPIO25 | Lid interlock switch | 10 kOhm pull-up plus 100 nF debounce |
| GPIO26 | Optical boil-over sensor | pull-up plus debounce |
| GPIO33 | Reservoir level switch | pull-up plus debounce |
| GPIO13 | SG90 servo | 50 Hz PWM |
| GPIO14 | Relay 1 (heater) | direct PID drive signal |

## I2C addresses

| Address | Device | Role |
|---|---|---|
| 0x3C | SSD1306 128x64 OLED | display |
| 0x76 | BMP280 | chamber pressure |
| 0x20 | PCF8574 #1 | Relay 2 to Relay 7 triggers and buzzer |
| 0x21 | PCF8574 #2 | status LEDs (red, amber, green, blue) |

## Relay assignment (Power Board)

| Relay | Load |
|---|---|
| 1 | 12 V silicone heater pad (50 W), PID |
| 2 | Vacuum (diaphragm) pump |
| 3 | Recirculation pump |
| 4 | Dispense pump |
| 5 | Water inlet solenoid |
| 6 | Lid lock solenoid |
| 7 | Exhaust fan (40 mm) |

## Inter-board link

The specification uses a 10-pin ribbon carrying power, I2C, the heater PID line and signals. The scripted PCB iterations moved both PCF8574 expanders onto the Control Board and widened the link to 16 pins; see [pcb-status.md](pcb-status.md).

## Notes

* GPIO34 is input-only on the ESP32, which suits an analog sensor.
* The relay stage is opto-isolated, which keeps inductive switching noise off the control ground.

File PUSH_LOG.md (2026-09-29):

# iKwath: Push Log

A record of what each push to the repository did and why, newest first. Versioned notes are in [CHANGELOG.md](CHANGELOG.md).

Branch: `main`

| # | Commit | Date | Version | Summary |
|---|---|---|---|---|
| 4 | `2bfe716` | 2026-09-30 | 0.4.0 | Documentation set, README restructure, status corrections |
| 3 | `7036a7b` | 2026-09-21 23:26 | 0.3.0 | Final KiCad PCB design files and schematics |
| 2 | `80da5cf` | 2026-09-21 22:59 | 0.2.0 | Web applications, assets and project architecture |
| 1 | `238240f` | 2026-09-21 22:57 | 0.1.0 | First commit: README specification |

---

## Push 4: Documentation and status corrections (`2bfe716`, v0.4.0)

**Status:** committed to `main`. Message:

```
v0.4.0: add ESP32 firmware draft, docs set, INSTALL, CHANGELOG, PUSH_LOG, project report; correct README status claims
```

**Files:** README rewritten; new `ino/` firmware folder and `models/` notebook; new `INSTALL.md`, `CHANGELOG.md`, `PUSH_LOG.md`, `SIH26048_PROJECT_REPORT.md` and ten files under `docs/`. `ps_shortlist.md` is also untracked and is included only if you want it on the remote.

| Area | What was done | Why |
|---|---|---|
| README | Restructured; layout now lists real folders; added a Built-versus-Designed table | Reviewers should see exactly what exists |
| Claims | Removed the unverified "zero-error" rule-check claim (detail lives in `docs/pcb-status.md`); stated that the app simulates extraction and the firmware is untested | Statements must match the files |
| Firmware | Added `ino/ikwath_firmware` (state machine, PID heater, mass endpoint, NFC profile, safety checks, serial and HTTP interface) | The control sequence now has an implementation to bench-test |
| Models | Added `models/ikwath_process_model.ipynb`; its energy balance shows the heater is undersized for the cycle-time target | Check design targets against each other before building |
| BOM | Total quoted with its assumption | The CSV column is ambiguous between line total and unit price |
| Docs | Engineering set derived from the research notes and README | Each subsystem has one place to read about it |

**Verification:** figures were read from the repository files (rule-check reports, `BOM.csv`, git history, folder listings). The firmware was written but not compiled or run.

**Follow-ups:** decide whether to un-ignore and push `blehpcb/` and `blehread/`; fix `.claude/launch.json`; run DRC on the committed `pcb/` project and record the result; compile and bench-test the firmware; record a measured brew log.

---

## Push 3: Final KiCad PCB design (`7036a7b`, v0.3.0)

2026-09-21 23:26 IST. 5 files, 40,568 insertions, all under `pcb/` plus a `.gitignore` change.

**What went in:** `ikwath.kicad_pro`, `ikwath.kicad_sch`, `ikwath.kicad_pcb`, `ikwath.kicad_prl`, `fp-info-cache`, and a KiCad local-history folder.

**Why:** put the hardware design under version control so the schematic and board could be shared and reviewed.

**State:** the committed board contains routed copper (hundreds of track segments) but its rule-check results were not recorded in the repository.

---

## Push 2: Web applications and assets (`80da5cf`, v0.2.0)

2026-09-21 22:59 IST. 67 files, 7,034 insertions.

**What went in:** `app/` (50 files: landing page, stylesheet, imagery, hero video, asset backup with restore script) and `website/` (14 files: interactive app with `app.js`, manifest, assets, README), plus `.gitignore` and a launch configuration.

**Why:** give the hardware idea a visible product and app story for the presentation, including a live-looking extraction dashboard.

**State:** both front ends are static and run without dependencies. The extraction dashboard is a simulator.

---

## Push 1: First commit (`238240f`, v0.1.0)

2026-09-21 22:57 IST. 1 file, 422 insertions.

**What went in:** `README.md` with the full specification: pharmacopoeial background, extraction physics, pod and NFC design, fluidics, dual-PCB architecture, pin map, safety system, control state machine, application design, BOM and citations.

**Why:** fix the design in writing before building.

---

## Template for the next entry

```markdown
## Push N: <title> (<hash>, vX.Y.Z)

Date and size: `git show --stat --format='%h %ad' HEAD`

What went in:
Why:
Verification:
Follow-ups:
```

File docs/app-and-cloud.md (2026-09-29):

# Applications and cloud

## What exists today

| Folder | Contents | Connects to a device? |
|---|---|---|
| `website/` | Mobile-style interactive app: `index.html` (screens, tabs, modals), `styles.css`, `app.js` (state machine, extraction simulator, greetings), `manifest.json` | No. Extraction is simulated in the browser |
| `app/` | One-page product site: appliance, pods, app, formulations, science, standards, sign-in and sign-up modals, product imagery and video | No |

Both use plain HTML, CSS and JavaScript with no dependencies and no build step.

### Behaviour of `website/`

* Logo intro that blurs into a login screen.
* Time-based greeting (morning, afternoon, evening, night).
* Active pod card that expands to switch between Triphala, Ayush and Dashamoola Kadha.
* Five-stage extraction: Soak, 85 C Boil, Reduce 4:1, Filter, Dispense, with a countdown, temperature dial, 400 to 100 mL gauge and a canvas curve pinned to the 85 to 90 C band.
* Notification bell, pod scanner viewfinder simulation, profile screen, Android frame toggle for screenshots.
* Profile and account values are placeholders.

## Intended architecture (design only)

```mermaid
graph TD
    subgraph Appliance
        HW[ESP32 controller]
        BLE[BLE GATT: provisioning]
        WIFI[WiFi: WebSocket / MQTT]
        HW --- BLE
        HW --- WIFI
    end
    subgraph Clients
        APP[Mobile app]
        DASH[Live brew dashboard]
        VAULT[Formulation vault]
        LOG[Dose compliance log]
        FLEET[Clinic fleet view]
        APP --> DASH
        APP --> VAULT
        APP --> LOG
        APP --> FLEET
    end
    subgraph Cloud
        BROKER[MQTT broker]
        CAT[Formulation catalogue]
        DB[(PostgreSQL)]
    end
    BLE -.-> APP
    WIFI <--> APP
    WIFI <--> BROKER
    BROKER <--> DB
    CAT -.-> HW
```

| Concern | Design |
|---|---|
| Pairing | BLE for first-time WiFi credential hand-off |
| Local control | WebSocket between phone and ESP32 on the same network, working without internet |
| Fleet telemetry | MQTT topic `device/{id}/telemetry`, published about every second |
| Pod profiles | NFC tag ID mapped to a certified formulation record cached on the phone |
| Records | batch number, extraction metrics and timestamp per dose for clinics |
| Manual profiles | advanced mode with an explicit "unverified profile" warning |

## What is missing to make it real

1. Firmware BLE service, WebSocket and MQTT topics. The sketch in `ino/` has an optional HTTP status and control interface (`/status`, `/start`, `/stop`); BLE and MQTT are not implemented.
2. A mobile client (React Native or Flutter) or wrapping the web app as a PWA (the manifest exists).
3. A backend and database for profiles and dose logs.
4. A certified formulation source; profiles today are illustrative.

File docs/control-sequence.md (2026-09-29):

# Control sequence

The machine cycle. A first-draft implementation is in [`ino/`](../ino/README.md); it has not yet run on the appliance, so this document remains the specification the firmware is checked against.

## State machine

```mermaid
stateDiagram-v2
    [*] --> Idle
    Idle --> PodDetect: pod inserted, lid latched
    PodDetect --> WaterFill: NFC profile valid
    WaterFill --> PreSoak: 400 mL metered
    PreSoak --> ActiveBoil: soak time elapsed
    ActiveBoil --> Dispense: mass loss reached
    Dispense --> Eject: dose delivered
    Eject --> Idle: pod in bin
```

## Steps

| # | Step | Actuators and sensors | Exit condition |
|---|---|---|---|
| 1 | Pod loading and interlock | limit switch, lid-lock solenoid (Relay 6) | lid closed and locked; NFC tag read |
| 2 | Water intake | inlet solenoid (Relay 5), HX711 load cell | 400 mL (or profile volume) by mass |
| 3 | Pre-soak | none active | 180 to 300 s per profile |
| 4 | Vacuum boil | heater (Relay 1, PID), vacuum pump (Relay 2), BMP280, DS18B20 | about 55 kPa reached; liquid held at 85 to 88 C |
| 5 | Recirculation and vapor stripping | recirculation pump (Relay 3), exhaust fan (Relay 7) | runs during the boil |
| 6 | Endpoint detection | load cell | 300 g (+/- 2 g) evaporated |
| 7 | Filter and dispense | dispense pump (Relay 4) | about 100 mL delivered at 55 to 60 C |
| 8 | Eject | SG90 servo | pod dropped to waste bin |

## Endpoint by mass

The boiler sits on a straight-bar load cell read by the HX711. With initial water mass m0, the loss is delta_m = m0 - m(t). At delta_m = 300 g (+/- 2 g) the 4:1 reduction is complete and the cycle ends. This replaces a fixed timer, so the endpoint tracks the actual evaporation rate.

## PID and supervisory checks

* Heater: PID drive on GPIO14 to hold the setpoint from the pod profile (85 to 88 C).
* Firmware supervision (specified): lid sense on GPIO25, boil-over on GPIO26, reservoir level on GPIO33, enclosure NTC on GPIO32, over-temperature on the DS18B20.
* Hardware protection does not depend on any of these; see [safety-system.md](safety-system.md).

## Items firmware must settle

* Load-cell calibration and tare handling with the chamber under vacuum (buoyancy and hose forces).
* Vacuum control law (bang-bang or proportional) and vent timing before dispense.
* Failure states: dry boil, lid opened mid-cycle, tag unreadable, sensor out of range.

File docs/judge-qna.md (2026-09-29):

# Anticipated questions

**Q1. Why not just simmer it on a stove?**
A classical Kwatha needs 45 to 60 minutes of attended simmering and is only fresh for a few hours, so people buy preserved syrups instead. iKwath aims to make a fresh, correctly reduced single dose on demand.

**Q2. Boiling faster usually means hotter. How do you stay within classical gentle heat?**
By lowering pressure rather than raising temperature. At 0.5 to 0.6 atm water boils at about 82 to 86 C, so the liquid boils vigorously inside the 85 to 90 C envelope. A wide shallow pan, recirculation and a vapor exhaust add speed without heat.

**Q3. How does the machine know when the decoction is done?**
By mass. A load cell tracks the chamber; when 300 g has evaporated from 400 g of water, the reduction is 4:1 and the boil stops. That follows the real evaporation rate instead of a fixed timer.

**Q4. Is it safe?**
Three protections act with the firmware off: a lid interlock and a 95 to 100 C bimetallic cutoff, both in series with the heater, plus a 5 A fuse on the 12 V rail. Firmware adds boil-over, level and over-temperature supervision on top. No mains-side safety review has been done yet.

**Q5. How do you know the drink matches classical Kwatha?**
We do not claim that yet. The design follows pharmacopoeial ratios, particle size and reduction, and it monitors dissolved solids as a consistency proxy. Extract quality has not been tested in a lab, and that is the main next step.

**Q6. Have you built it?**
The hardware is specified in detail, the PCBs exist in several KiCad iterations, a first-draft ESP32 firmware implements the full cycle, and two web front ends are runnable. The firmware has not yet run on the appliance, and a physical prototype is not built. The dashboard's brew is a simulation. `docs/limitations.md` lists the gaps and how to close each.

**Q7. What does a pod add?**
Dose accuracy (a pre-measured, particle-graded charge), a built-in filter, and an NFC tag carrying the brew profile so the machine picks the right ratio, soak, temperature and reduction. It also gives a route to traceability.

**Q8. What does the appliance cost to build?**
The prototype electronics come to about INR 4,588 by the bill of materials, excluding enclosure, chamber, food-grade parts and PCB fabrication. The figure needs a spot-check against supplier prices.

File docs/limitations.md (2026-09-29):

# Limitations and what is needed to close them

| # | Limitation | Consequence | What closes it |
|---|---|---|---|
| 1 | Firmware is a first draft (`ino/`) | The control sequence and safety supervision are written but have not run on the appliance | Compile, bench-test each subsystem, then calibrate the values marked CALIBRATE in `config.h` |
| 2 | No physical prototype tested | The 9 to 12 minute cycle, 85 to 90 C envelope and 300 g endpoint are design targets, not measurements | Build the rig, log temperature, pressure and mass for full cycles, publish the curves |
| 3 | No extract quality data | Nothing shows the decoction matches classical hand preparation | Have samples analysed (extractive value, TDS versus reference, HPTLC fingerprint) at a certified lab |
| 4 | Web apps simulate the brew | The dashboard is illustrative and connects to nothing | The sketch offers an optional HTTP status and control interface; point the app at it, then add BLE and MQTT |
| 5 | Cloud, mobile client and catalogue are design only | No backend, no real formulation database | Build a small backend and source certified profiles |
| 6 | PCB not finalised | Several iterations exist; rule-check clean-up and routing are still open on some | Pick a variant, fix footprints, finish routing, store the final DRC and ERC reports |
| 7 | Bill of materials is prototype grade | Not food-grade or certified; enclosure, chamber and tooling not costed | Re-source food-contact parts and add mechanical costs |
| 8 | Vacuum plus load cell interaction untested | Chamber pressure and hose forces may bias the mass reading | Characterise with a static test under vacuum; add tare and compensation |
| 9 | Mains-side design unreviewed | Creepage, clearance and grounding not checked by a qualified person | Independent electrical review before any powered test |
| 10 | Heater power budget does not match the cycle-time target | Evaporating 300 g needs about 690 kJ of latent heat, and warming the water adds about 100 kJ. The 50 W heater in the bill of materials would need hours; a 12 minute cycle needs on the order of 1.4 kW into the water (`models/ikwath_process_model.ipynb`) | Choose a mains-rated heating element and rate the relay, wiring, cutoff and fuse for it, or reduce the evaporation target, or relax the cycle-time claim |
| 11 | Water volume versus pod charge | A 25 g pod at the herb-class ratios (16, 8, 4) needs 400, 200 or 100 mL of water, while the profile fixes 400 mL | Decide whether volume follows the class ratio or the pod charge changes with class, then align the profile, firmware and docs |
| 12 | Repository hygiene | `blehpcb/` and `blehread/` are gitignored; `.claude/launch.json` points to a missing folder; `pcb/.history` has a nested repository | Decide what to publish, fix the launch file, remove or ignore the nested repository |

## Scope statement

iKwath is a prototype concept for a standardised decoction appliance. It is not a certified medical or food-contact device, and nothing here is a health claim.

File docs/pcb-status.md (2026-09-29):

# PCB status

The repository holds several iterations of the electronics. This page records what each contains and what its own reports say. Figures are copied from the report files; nothing here is a new measurement.

## Where the boards live

| Location | In git? | What it is |
|---|---|---|
| `pcb/` | yes (commit `7036a7b`) | KiCad project: `ikwath.kicad_sch`, `ikwath.kicad_pcb`, `ikwath.kicad_pro`. Contains routed copper (about 430 track segments). No rule-check report is stored with it. |
| `blehpcb/ikwath-control-board/`, `blehpcb/ikwath-power-board/` | no (ignored) | Generated KiCad 8 projects from `blehpcb/generate_final_kicad8.py`, with `*-drc.rpt` and `*-erc.rpt` |
| `blehpcb/pcbreal/` | no (ignored) | Scripted placement, routing and stackup iterations (`place_components.py`, `route_signals.py`, `stackup_and_planes.py`, `finish_board.py`), with Specctra `.dsn` and `.ses` files from an autorouter |

## Reported rule-check results

| Variant | ERC | DRC | Unconnected pads |
|---|---|---|---|
| `blehpcb/ikwath-control-board` | 0 errors, 64 warnings | 371 violations | not itemised |
| `blehpcb/ikwath-power-board` | 0 errors, 52 warnings | 259 violations | not itemised |
| `blehpcb/pcbreal/control-board` (`control-board.drc.rpt`) | | 1 violation | 56 |
| `blehpcb/pcbreal/control-board` (`DRC.rpt`, later run) | | 2 violations | 4 |
| `blehpcb/pcbreal/power-board` | | 5 violations | 62 |

What dominates the larger reports:

* Control board (371): clearance 152, silkscreen over copper 67, solder-mask bridge 52, silkscreen overlap 35, footprint mismatch 32, shorting items 21.
* Power board (259): silkscreen overlap 105, silkscreen over copper 59, clearance 33, library-footprint issues 21, solder-mask bridge 20, shorting items 12.
* The ERC warnings and many DRC items trace to footprints that are not found in the standard libraries (for example the ESP32 module footprint, terminal blocks and the fuse holder).

## Reading these honestly

* Earlier drafts of the README described the reports as zero-error. They are not: only ERC has 0 errors, and the DRC counts above are not zero.
* The later `pcbreal` reports (1 to 5 violations, 4 to 62 unconnected pads) are much cleaner than the `ikwath-*-board` reports, but they still have unrouted nets on the power board, and it is not recorded which variant is intended to be final.
* `shorting_items` entries must be examined before fabrication; they can indicate real overlaps.

## Known deviations from the specification (from the scripted iterations)

* Both PCF8574 expanders sit on the Control Board, so the inter-board link grew from 10 to 16 pins.
* The ESP32 is a socketed 2x19 header footprint rather than a soldered module; verify the pin order against your specific DevKit before soldering.
* Connectors are generic 2.54 mm headers rather than JST-XH.
* Generated board outlines are larger than the 70 x 60 mm and 80 x 70 mm in the specification.

## Before sending to a fabricator

1. Choose one variant and copy it into `pcb/` (or replace `pcb/`).
2. Assign real library footprints to every part reported as missing.
3. Route the remaining nets, then run DRC until only intended items remain.
4. Review clearances and creepage on the mains-side traces with a qualified reviewer.
5. Store the final DRC and ERC reports next to the board in git.

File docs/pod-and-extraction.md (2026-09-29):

# Pod design and extraction physics

## Kwatha in one paragraph

Kwatha (Kashaya, Kadha) is the classical aqueous decoction: coarse powder (yavakuta churna) boiled in a multiple of water and reduced, then strained. It is not shelf-stable, so the value of iKwath is making a fresh, correctly reduced dose as easy as a capsule machine.

## Pharmacopoeial parameters

| Herb class | Botanical parts | Water ratio | Reduction | Concentration |
|---|---|---|---|---|
| Soft (Mridu) | leaves, flowers, tender herbs | 16 parts | to 1/4 | about 4x |
| Medium (Madhyama) | bark, stems, soft wood | 8 parts | to 1/4 | about 2x |
| Hard (Kathina) | roots, dense heartwood | 4 parts | to 1/4 | about 1x |

Outpatient working profile: 400 mL of water reduced to 100 mL (4:1 by volume).

## Particle size (PCIM&H AFI/2020/KC/1.0)

* 100 percent through IS sieve 22 (710 micron).
* No more than 10 percent through IS sieve 44 (355 micron).
* Reason: coarse granules let water penetrate without forming an impermeable bed, and avoid fine colloidal solids that would clog the mesh and cloud the drink.

## Temperature versus speed

Classical texts call for gentle heat (Manda Agni). Above 100 C volatile terpenes and thermolabile glycosides degrade. The design goal is to cut a 45 to 60 minute simmer to about 9 to 12 minutes while liquid stays at or below 85 to 90 C. The levers:

1. **Reduced pressure.** At 0.50 to 0.60 atm absolute (50 to 60 kPa) water boils at roughly 81 to 86 C. It boils vigorously, with convection, inside the temperature ceiling.
2. **Surface area.** A wide shallow pan (150 to 200 cm2) instead of a tall pot (about 50 cm2) roughly triples the evaporating surface.
3. **Boundary-layer stripping.** A small blower removes humid air from above the liquid.
4. **Recirculation.** A pump sprays liquid over the pod bed, removing diffusion boundary layers and hot spots.

These are design targets from the physics; no measured cycle time exists yet (see limitations).

## Pod

| Item | Specification |
|---|---|
| Charge | 25 to 35 g dry coarse herb |
| Filter | integrated mesh, 150 to 250 micron, keeps particles above 355 micron out of the drink |
| Shell | food-grade polypropylene or pressed cellulose, BPA-free, rated to 100 C in water |
| Seals | hermetic foil top and base seals |
| Identity | NTAG213 NFC tag (13.56 MHz) on the rim, read by an MFRC522 |

### NFC payload (design)

Formulation ID, herb-class water ratio (16:1, 8:1 or 4:1), pre-soak time (180 to 300 s), target evaporated mass, temperature setpoint (85 to 88 C) and target extract density (TDS or Brix threshold).

## Quality proxy

Total dissolved solids are read inline with an analog TDS sensor. This is a consistency proxy only. Marker fingerprinting (HPTLC) and quantitative extractive value (percent w/w) require a certified laboratory.

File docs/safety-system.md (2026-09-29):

# Safety system

The appliance boils water above a mains-derived heater, so protection is layered and does not rely on firmware.

## Hardware layers (independent of the microcontroller)

```mermaid
graph LR
    V12[12V rail] --> F1[F1: 5A fuse]
    F1 --> TB10[TB10: lid interlock]
    TB10 --> K1[Relay 1 NO contact]
    K1 --> F2[F2: bimetallic cutoff 95-100 C]
    F2 --> HTR[Heater element]
    HTR --> GND[Ground]
```

| Layer | Part | Protects against | Behaviour |
|---|---|---|---|
| 1 | F2 bimetallic thermal cutoff, 95 to 100 C, on the boiler wall, in series with the heater | dry boil, firmware fault, welded relay contacts | snap-disc opens and breaks the heater circuit |
| 2 | TB10 lid microswitch, in series with the heater feed | steam and burn exposure when the lid opens | heater power cut in hardware |
| 3 | F1 5 A fast-acting cartridge fuse on the 12 V rail | short circuits, pump stall | blows |

Because the layers are in series with the heater, any one of them removes heat even if the ESP32 is hung, unpowered or mis-programmed.

## Firmware supervision (drafted in `ino/`, not yet run on the appliance)

| Signal | Pin | Intended action |
|---|---|---|
| Lid sense | GPIO25 | abort cycle, heater off |
| Optical boil-over | GPIO26 | heater off, vent |
| Reservoir level | GPIO33 | refuse to start or stop the cycle when low |
| Enclosure NTC | GPIO32 | derate or stop on over-temperature |
| Liquid temperature | GPIO4 | hold 85 to 88 C, trip above the envelope |

## Other design points

* Opto-isolated relay drive and a separate Power Board keep switching noise and mains-side wiring away from the analog sensors.
* Heater traces on the Power Board are specified at heavy-copper width (1.5 to 1.8 mm).
* Food-contact parts (chamber, tubing, pump heads, pod shell) must be food-grade; the BOM lists hobby-grade parts for the prototype only.

## Not covered

No electrical-safety or medical-device certification work has been done, and mains wiring should be reviewed by a qualified person before any powered test.

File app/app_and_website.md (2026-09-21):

# iKwath — App & Website

> Companion to [research.md](research.md), [structure.md](structure.md), [pcb.md](pcb.md).

---

## 1. Why the app matters to the judges (don't treat it as an afterthought)
The PS is a hardware PS, but SIH panels consistently reward teams that show a **full system story** — device + control/monitoring layer + a plausible path to real-world deployment (clinics, Ayush pharmacies, homes). The app is also where you demonstrate the two things text alone can't: **live sensor data during your demo video** (temperature/pressure/weight graphs proving the 85–90°C claim in real time) and **the pod-certification/traceability business model** (AIIA/PCIM&H-certified formulation profiles flowing from a backend into the device).

---

## 2. System components

| Component | Purpose | Recommended stack |
|---|---|---|
| **Mobile app** (primary control surface) | Pair with device (BLE for setup, WiFi for ongoing), select/confirm formulation, start cycle, live-monitor stage/temperature/time, dose history, clinic mode | React Native or Flutter (cross-platform, fast to build for a hackathon demo on one phone) |
| **Device firmware ↔ app link** | Telemetry + control commands | BLE for initial WiFi provisioning + local/offline control; WiFi (MQTT or simple REST/WebSocket to a local or cloud broker) for live streaming once connected | 
| **Backend / cloud** | Store pod formulation profiles (synced from AIIA/PCIM&H certified database), user accounts, dose logs, device fleet management (for clinic deployments with multiple units) | Node.js/Express or FastAPI + PostgreSQL; MQTT broker (e.g., Mosquitto/AWS IoT Core) for device telemetry at scale |
| **Website** | Public-facing product site + a light admin/clinic dashboard | Simple marketing site (product story, science/API-AFI credibility section, pods catalogue) + a web dashboard for clinics/pharmacies to manage multiple units and formulation stock |

---

## 3. Mobile app — feature table

| Feature | Description | Priority |
|---|---|---|
| **Device pairing (BLE → WiFi)** | Standard onboarding: scan for device, connect BLE, hand off WiFi credentials, device joins home/clinic network | Must-have |
| **Pod scan confirmation** | When user inserts a pod, app shows formulation name, dose, expected cycle time, reduction target — pulled from the NFC tag ID cross-referenced with the certified formulation database (cached locally, synced from cloud) | Must-have |
| **Live cycle dashboard** | Real-time stage indicator (soak/heat/reduce/filter/dispense), live temperature graph (line chart pinned to the 85–90°C band so users/judges visually see it never crossing the line), live pressure reading (if vacuum-assist implemented), countdown timer, extract-density progress toward reduction target | **Must-have — this is your strongest demo asset** |
| **Manual override / custom profile (advanced/clinic mode)** | For Ayurvedic physicians/pharmacists to adjust ratio/time within safe bounds for a formulation not yet pod-certified, with a clear "unverified profile" warning | Nice-to-have, shows depth |
| **Dose history & compliance log** | Log of every dose made — formulation, timestamp, extract density achieved, dose volume — useful for home users tracking a prescribed course, and for clinics for patient records | Should-have |
| **Reminders/scheduling** | Remind user to take a dose per their prescribed Ayurvedic regimen (e.g., before/after meals, specific times) | Nice-to-have |
| **Formulation library/catalogue** | Browse available certified pod formulations, their indications (from AFI monograph text), contraindications | Should-have |
| **Cleaning/maintenance reminders** | Prompt rinse cycle, filter replacement, descaling based on cycle count | Should-have |
| **Error/fault alerts** | Push notification on any safety fault (boil-over, dry-run, lid not sealed, pressure fault) with plain-language explanation | Must-have (ties directly to your safety story) |
| **Multi-device/clinic mode** | For an Ayush OPD/pharmacy running several units, a dashboard view of all machines' status, pod stock levels, usage analytics | Nice-to-have — strong "impact & scalability" slide material |
| **Offline mode** | Device can run a cycle standalone (physical buttons + onboard display) even with no app/network connection — app is a convenience layer, not a dependency | Must-have (mention explicitly — judges probe "what if wifi fails" during demos) |

---

## 4. Website — sections

| Section | Purpose |
|---|---|
| **Home/hero** | "Fresh, standardized Kwatha in minutes — not hours" — problem/solution framing |
| **How it works** | Visual process flow (pod in → soak → controlled boil → reduce → filter → dispense), reuse the process table from research.md |
| **The science** | Explain the AFI/API standard, the 85–90°C constraint, and the reduced-pressure evaporation mechanism in accessible language — this is your credibility section for Ayush-literate visitors/evaluators who click through |
| **Pods** | Catalogue of certified formulations, each with AIIA/PCIM&H certification badge/reference |
| **For clinics/pharmacies** | B2B pitch: consistency, anti-adulteration, throughput for OPD dispensing, fleet dashboard | 
| **For home use** | B2C pitch: convenience, freshness, dosing accuracy for patients on a prescribed Ayurvedic regimen |
| **Team/about** | SIH team info (for the submission/portal linkage) |
| **Admin/clinic dashboard (web app, gated login)** | Manage multiple devices, view fleet status, manage pod inventory/reorder, view aggregated dose analytics, push firmware/formulation-profile updates to devices |

---

## 5. How the app controls the PCB/device — protocol detail (for your technical-approach slide)

| Layer | Detail |
|---|---|
| **Provisioning** | BLE GATT service on ESP32 exposes WiFi-credential-write characteristic; app scans/connects via BLE, writes SSID/password, device reboots onto WiFi |
| **Ongoing control (local network)** | Device runs a lightweight local WebSocket/MQTT client; app on the same network talks to it directly (low latency, works without internet) — good "offline-first" story |
| **Ongoing control (remote/cloud)** | Device also connects to a cloud MQTT broker for remote monitoring/fleet management (clinic use case) — publishes telemetry topics (`device/{id}/temp`, `/pressure`, `/stage`, `/weight`) and subscribes to a command topic (`device/{id}/cmd`) |
| **Commands app → device** | `start_cycle(pod_id)`, `pause`, `abort`, `manual_override(params)` (gated), `run_rinse_cycle` |
| **Telemetry device → app** | Streamed every 1–2 seconds during an active cycle: stage, temperature, pressure (if vacuum), weight, extract density estimate, time remaining |
| **Formulation profile sync** | Device caches a local table of known pod-formulation profiles (ratio, time, temp, reduction target) keyed by NFC ID; app/backend syncs new/updated certified profiles down to the device whenever connected, so pod recognition still works offline for previously-seen formulations |

---

## 6. Demo-video framing tip (ties back to research.md §2.3)
Show the **live app temperature graph on screen next to the physical device** while it's actively reducing — this single shot does more to prove "we didn't fake the 85–90°C claim" than any slide of text. Also show the **NFC tap → formulation name pop-up on the app** as the very first interaction in your demo — it's a satisfying, legible "smart" moment for a judge watching at 1x speed.

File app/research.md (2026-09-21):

# iKwath — SIH 2026 Research Dossier (PS 26048)

> Ministry of Ayush / All India Institute of Ayurveda (AIIA) · Hardware · MedTech/BioTech/HealthTech
> Last updated: 2026-09-18

---

## 1. Understand the problem before anything else

### 1.1 What a Kwatha actually is
Kwatha (kashaya/kadha) is the classical Ayurvedic **aqueous decoction**: coarse powder (yavakuṭa cūrṇa) of one or more herbs is boiled in water, reduced down, and strained. It is the most prescribed Ayurvedic dosage form and, critically, **it must be drunk within a few hours of preparation** — it isn't shelf-stable like an arishta or a churna tablet. That single fact is the whole business case for iKwath: people can't/won't make it fresh at home correctly, so they buy concentrated shelf-stable syrups that are weaker and easier to adulterate. Your device exists to make "fresh, correct-dose Kwatha" as easy as a Nespresso shot.

### 1.2 The classical preparation rule (API/AFI general method)
This is the exact mechanism the jury will expect you to know cold — quote it, don't paraphrase it vaguely.

**Standard API (Ayurvedic Pharmacopoeia of India) general rule for Kwatha:**

| Drug hardness (per yavakuṭa cūrṇa) | Water added (parts, by weight of drug) | Boiled & reduced to | Effective concentration factor |
|---|---|---|---|
| Soft / leafy / flower drugs | 16 parts water | 1/4 part (i.e. to ¼ of the *added water*, not of drug) | ~4x |
| Medium-hard drugs (stems, barks) | 8 parts water | 1/4 part | ~2x |
| Hard drugs (roots, heartwood) | 4 parts water | 1/4 part | ~1x |

Your PS statement simplifies this to a single working case: **~400 mL water → 1 litre boiling chamber → reduced to ~100 mL dose (a 4:1 reduction)**, which corresponds to the "soft drug, 16-parts-water" class — the most common category in outpatient formulary use. Design your default profile around this, but your pod's encoded profile (see §3) must be able to override the ratio and reduction target per formulation, because hard-drug decoctions use a different starting ratio.

**Powder grade (yavakuṭa cūrṇa) — PCIM&H AFI/2020/KC/1.0 spec:**

| Parameter | Spec |
|---|---|
| Passes through | IS Sieve No. 22 (710 µm) — **100% must pass** |
| Retained coarse fraction | Not more than 10% passes through IS Sieve No. 44 (355 µm) — i.e., it must stay *coarse*, not powder-fine |
| Purpose of grade | Coarse grind maximizes surface area for extraction while still being retainable by a straining cloth/pod mesh |

This directly informs your pod mesh design (§ below): the pod's internal filter mesh should be sized to *just* retain 355–710 µm particles without choking flow — think ~150–250 µm mesh, similar order to a French-press/tea-pod mesh, not a coffee paper filter.

### 1.3 The real engineering problem (read this twice — it's what separates finalist teams from eliminated ones)
The PS is *not* "build a kettle with a timer." It is an **extraction kinetics problem constrained by a pharmacopoeial identity test.** Read the Expected Solution section again: *"any acceleration has to be validated to reproduce the classically prepared decoction's extract density and constituent profile."* That means:

1. You cannot just crank the heat to boil faster — Ayurvedic decoctions are traditionally prepared at a **gentle/mild boil (~85–90°C, i.e. sub-100°C, "manda agni")**, not a rolling boil, because many actives (glycosides, volatile constituents, certain alkaloids) degrade or volatilize at/above 100°C or with prolonged high heat. The PS explicitly caps you at 85–90°C.
2. The real bottleneck is **time**, not temperature. A classical kwatha takes 20–45+ minutes because reduction (4:1 evaporation) at atmospheric pressure and near-100°C is slow by nature (evaporation rate ∝ surface area × vapor pressure gradient, roughly). To cut cycle time *without* raising temperature, you must attack the **other variables** in the evaporation rate equation:
   - **Surface area** — spread the 400 mL into a thin film/large-surface geometry instead of a deep pool (a shallow wide pan evaporates far faster than a tall narrow cup for the same volume).
   - **Vapor removal** — actively pull humid air away from the liquid surface (a small fan/forced convection over the surface, or a vent with airflow) so the boundary layer doesn't saturate and stall evaporation.
   - **Agitation/recirculation** — continuously stir or recirculate the liquid through the powder bed so extraction isn't diffusion-limited; this also prevents hot-spots and scorching, and speeds mass transfer independent of bulk temperature.
   - **Reduced pressure (vacuum-assisted boiling)** — this is your strongest lever. Water boils at ~85–90°C when pressure is dropped to roughly 0.5–0.6 atm (~55–65 kPa absolute, per steam tables). Pulling a **mild, food-safe vacuum** with a small diaphragm/vacuum pump lets you boil vigorously (fast evaporation, fast reduction) while the liquid temperature never exceeds ~85–90°C — this is literally rotary-evaporator (rotovap) principle, used industrially to concentrate heat-labile herbal extracts without degrading them. **This is almost certainly the "correct" hero mechanism the PS is hinting at** with the line *"reduced-pressure (lower-temperature) evaporation."* Build your differentiator around this.
3. Whatever speed-up method you choose, the PS explicitly wants a **validation story**: constituent profile (qualitative, e.g. TLC/HPTLC fingerprint or marker-compound match) and extractive yield (quantitative, e.g. % w/w extractive value per API test methods, or extract density via refractometer/Brix as an on-device proxy) must match the classical 45–60 min preparation. You will not be able to do real HPTLC in a hackathon, but you MUST show in your PPT/report that you *understand* this is the actual success metric, and propose extract density monitoring (see §5 sensors) as your real-time proxy control variable — this is explicitly invited by the PS text ("the appliance monitors weight and extract density so every dose is consistent").

### 1.4 Why "pod-based" — and what problem it solves besides convenience
- **Dosing accuracy & adulteration**: a sealed, certified pod removes the two biggest failure points of home/clinic kwatha — wrong powder grade and wrong quantity.
- **The pod doubles as the brew-bag/filter**, so there's no loose powder to clean and no risk of fine particulate carrying into the dose (important because fine particulate in a decoction is itself an API-defined defect).
- **Formulation flexibility**: AIIA/OPD Ayurvedic pharmacies stock dozens of kwatha churna formulations (Dashamoola, Trikatu-based, Guduchi, etc.) — a pod system means one appliance serves all of them, the pod just carries the *profile* (ratio, temperature ramp, time, reduction target) as data.
- **Certifiability**: the PS says pods "are certifiable against the API/AFI by AIIA/PCIM&H" — meaning your business model piggybacks on an existing regulatory pathway (like how Nespresso pods are QC'd at the factory, not by the consumer).

---

## 2. SIH-specific strategy (how selection actually works — read this before designing)

### 2.1 The stage that actually eliminates most teams is the **idea/PPT round**, not the grand finale
- SIH runs in two effective gates: (a) internal college shortlisting / SIH portal idea submission (PPT, ~6 slides, PDF only), and (b) if selected, the 36-hour Grand Finale hackathon with a working prototype demo.
- On a popular PS, 400–500+ teams may submit for as few as 5-ish seats at the internal round — **decided purely by a 6-slide PDF, no live pitch, no demo.** This means your PPT has to stand entirely on its own: no verbal narration will save a confusing slide.
- Because PS 26048 is a Ministry of Ayush hardware PS with real pharmacopoeial depth (not a generic "app for X" PS), it is likely to attract **fewer but more technically serious teams** than trendy software PS's. That is an advantage for a team that goes deep on the actual pharmaceutics — most competing teams will treat it as "a kettle with an app" and miss the extraction-kinetics/validation angle entirely. Winning strategy: **be the team that clearly understands API/AFI pharmacognosy, not just electronics.**

### 2.2 PPT/idea submission format rules (follow exactly — deviation risks disqualification)
- **Strict slide limit** (commonly 6 slides in the official AICTE/SIH template) — do not add slides, do not change the provided template's fonts/theme.
- **PDF only.** No PPTX, no Word doc uploads accepted by the portal.
- Content should be **visual and information-dense, not paragraph-dense** — diagrams, flow charts, exploded views, block diagrams, tables (like the ones in this doc) score far better than prose bullets.
- Typical mandated sections (map directly onto slides):
  1. **Title slide** — PS ID/title, team name, team leader, category (Hardware).
  2. **Problem understanding & idea/proposed solution** — restate the AFI/API constraint in your own words + your one-line solution ("pod-based vacuum-assisted rapid decoction maker").
  3. **Technical approach** — block diagram: mechanical + electronics + firmware + app, and your process flow (soak → vacuum-assisted controlled boil → reduce → filter → dispense).
  4. **Feasibility & viability** — risks (heat-labile actives, vacuum seal cost, pod cost/certification) + mitigation.
  5. **Impact & benefits** — clinics/OPDs, elderly/home users, standardization & anti-adulteration, Ayush export/panchakarma centers.
  6. **Research/references** — cite PCIM&H AFI/2020/KC/1.0, API monographs, AIIA — this signals domain rigor to Ayush-affiliated evaluators.

### 2.3 How SIH actually "reads" your PDF/watches your video — practical implications
- Portal submissions are typically reviewed as **rendered PDF pages** by human evaluators (nodal-officer/SPOC panels, plus domain experts from the sponsoring ministry) — assume a **human skims each slide for 15–30 seconds**, not that an AI/OCR engine "scans for keywords." That said:
  - Use **real text, not text-baked-into-images** for headings/body — some portals/evaluator tools do run keyword/plagiarism checks and copy-paste text extraction across submissions; an unselectable PDF (flattened image-only slide) can fail those automated similarity/keyword passes and looks lazy to a human reviewer besides.
  - Keep file size reasonable; portals often cap upload size (~5–10 MB) — compress images/diagrams.
  - Filename convention matters cosmetically — follow whatever the portal specifies (often `PSID_TeamName.pdf`).
- **Video round** (used at Grand Finale / some ministry-specific pre-screening rounds, and always useful to have ready): assume it is **watched at 1x by a person**, often multiple videos back-to-back in a review sprint — so:
  - Keep it **2–4 minutes**, hook in the first 10 seconds (don't open with a team intro; open with the problem — "a fresh kadha degrades in hours, but making one correctly takes 45 minutes and a trained hand").
  - Show the **physical device working** on camera as early as possible — judges are checking "is this real or just a rendering?" A CAD render alone reads as vaporware; even a rough 3D-printed shell with visible internals earns more trust than a polished animation.
  - Overlay **captions/labels** on screen (pod insertion, vacuum stage, temperature readout, dispensed dose) — most judges skim with sound off in a first pass.
  - Never hardcode/fake a demo value — cut a visible sensor reading (temperature, weight) into frame; a judge who suspects a staged number will mark down "feasibility."
  - End with impact numbers (cycle time achieved vs classical 45–60 min, e.g. "9–12 min," dose consistency ±X%) — quantified claims outperform adjectives.

### 2.4 Who evaluates PS 26048
SIH does not publish individual evaluator names publicly before the event, and no name-level information exists yet for SIH 2026 at the time of this research. What is knowable and should shape your prep:
- The **sponsoring organization is Ministry of Ayush, department All India Institute of Ayurveda (AIIA)** — evaluation panels for ministry-sponsored PS's are typically staffed by a mix of: (a) the ministry's own nodal officer/SPOC for that PS, (b) subject-matter experts from the sponsoring institute (here, likely AIIA faculty/Ayurvedic pharmaceutics or Rasa Shastra & Bhaishajya Kalpana department scientists, and possibly PCIM&H standardization scientists since the PS explicitly names PCIM&H certification), and (c) AICTE/SIH-appointed technical mentors (usually academics/industry engineers) for the hardware/electronics side.
- **Practical implication**: your panel is very likely **half pharma-science literate, half engineering literate.** Don't over-index on pure electronics flexing (a beautiful PCB won't matter if you show boiling temperature 100°C and confidently call it "standard") — pair every engineering claim with the correct pharmacopoeial term (yavakuṭa cūrṇa, extractive value, manda/madhyama agni) so both halves of the panel see you did the homework.
- Cross-check the official channel closer to the deadline: `sih.gov.in` publishes the SPOC/mentor list per PS during the mentorship phase — monitor it, don't guess further.

### 2.5 General "hacks" that consistently separate winning SIH teams (cross-referenced across multiple winner write-ups/playbooks)
1. **PS selection asymmetry** — a technically deep PS with a real institutional sponsor (like this one) draws fewer copy-paste "ChatGPT idea" teams than trendy software PS's; lean into the depth rather than trying to look "more techy."
2. **Depth over buzzword density** — judges explicitly call out that cramming in AI/ML/blockchain buzzwords without grounding in the actual problem backfires; anchor every feature to the PS's literal Expected Solution bullets.
3. **A working, ugly prototype beats a beautiful non-working render.** For hardware PS's this is even more true — bring a physical unit that visibly boils/reduces/dispenses, even if the enclosure is 3D-printed/unpainted.
4. **Never let a hardcoded/rigged demo be visible** — panels actively probe for this; feed it a different pod/parameter live if asked.
5. **Time-box every pitch section** — presentations that run over get cut off mid-technical-explanation before the "impact" slide is ever seen; rehearse to finish under the limit with margin.
6. **Always carry an offline backup** (recorded video + PDF on a USB, no dependency on venue wifi) — connectivity failure is a recurring reason strong teams under-deliver live.
7. **Quantify impact** — cycle-time reduction %, cost per dose vs commercial arishta, number of AIIA/Ayush OPDs as addressable market, etc. Numbers read as credibility.

---

## 3. System overview — process table (powder in → dose out)

| Stage | What happens | Target parameter | Sensors/actuators involved |
|---|---|---|---|
| **1. Pod insertion & ID** | User inserts single-dose pod (contains yavakuṭa cūrṇa of the formulation) into the pod bay; lid closes and locks | Pod formulation profile read | RFID/NFC or barcode reader on pod, lid microswitch + solenoid lock |
| **2. Water fill** | Appliance meters ~400 mL potable water (API Jala standard) into the 1 L boiling chamber, wetting the pod | Water volume per profile (varies by formulation ratio) | Water level sensor / flow meter, inlet solenoid valve, load cell (weight-based confirmation) |
| **3. Soak** | Powder is allowed to hydrate for a short pre-soak (improves extraction rate before heat is applied) | 3–5 min, ambient–40°C | Temperature sensor (chamber), timer (firmware) |
| **4. Controlled mild boil** | Heater brings liquid to 85–90°C and holds; vacuum pump (if used) drops chamber pressure so boiling occurs at this temperature without exceeding it | 85–90°C, held within pressure/temp band | PT100/thermistor probe, heating element, vacuum pump + pressure sensor, PID control loop |
| **5. Active reduction** | Liquid is reduced from ~400 mL to ~100 mL (4:1) via continuous mild boil + forced vapor removal (fan/vent) + optional recirculation pump to keep extraction diffusion-limited-free | Reduce to ¼ volume / target extract density (Brix) | Load cell (mass-loss tracking = evaporated volume proxy), optical/refractometric density sensor, small extraction fan/vent, recirculation micro-pump |
| **6. Filter** | Reduced liquid is drawn/pressed through the pod's integrated mesh filter, separating spent powder from clear decoction | Particulate-free dispense | Pod mesh (150–250 µm), outlet pump/solenoid |
| **7. Dispense** | ~100 mL warm, fresh decoction dispensed into user's cup | ~100 mL ± tolerance, drinkable warm temp (~50–60°C) | Load cell (dose volume/weight confirmation), outlet valve |
| **8. Eject & clean** | Spent pod ejected into waste bin; boiling chamber + filter get a rinse cycle (dishwasher-safe parts removable) | Chamber clean for next cycle | Pod ejector mechanism, rinse-water solenoid |
| **Safety, throughout** | Anti-boil-over (foam/level sensing cuts heater), dry-run protection (no-water lockout), over-pressure/vacuum relief | Fail-safe at all times | Level/foam sensor, dry-run thermal cutoff, pressure relief valve |

### 3.1 Managing the "temperature must not exceed 85–90°C" constraint — how you actually do it
This is the single most-scrutinized engineering claim in your project. Present it as **three complementary control layers**, not one:

1. **Closed-loop PID temperature control** (baseline, cheapest, every team will have this): a food-grade thermistor/PT100 in the liquid feeds a PID loop driving the heater (PWM via SSR/MOSFET) to hold 85–90°C. This alone prevents *overshoot* but does not, by itself, speed up reduction — atmospheric boiling point of water is 100°C, so at 85–90°C you're not even boiling, just evaporating slowly (like a warm cup). This is the naive approach and explains why classical kwatha takes 45+ minutes.
2. **Reduced-pressure (vacuum-assisted) boiling — your differentiator**: use a small food-safe diaphragm vacuum pump to drop the sealed chamber to roughly 0.5–0.6 atm absolute. At that pressure, water's *boiling point itself* drops to ~85–90°C (standard steam-table relationship), so the liquid can **actually boil vigorously** (fast bubble-driven evaporation, fast reduction, fast extraction) while never thermally exceeding the 85–90°C ceiling the PS specifies. This is the same working principle as a rotary evaporator (rotovap) used in labs/industry to concentrate heat-sensitive extracts. State this explicitly in your PPT — it shows you solved the "shorten time without altering quality" requirement with a real physical mechanism, not just "better firmware."
3. **Surface-area + forced vapor removal + recirculation** (secondary boosters, cheap to add, compound with #2): a shallow/wide evaporation tray geometry inside the chamber, a small extraction fan pulling humid air off the liquid surface (vented outside, condensate optionally captured/discarded — do not let condensate drip back and dilute the dose), and a small recirculation pump continuously pushing liquid through the pod bed so extraction isn't diffusion-limited. None of these raise temperature — they only speed mass transfer.

**Anti-overheat safety net**: independent of the control loop, add a hardware thermal cutoff (bimetallic or thermal fuse rated ~95–100°C) in series with the heater as a fail-safe — this is standard appliance safety practice and a evaluator will expect to see it even briefly mentioned.

### 3.2 On-device validation proxy (answers "how do you know the dose is still correct?")
You cannot run HPTLC on a countertop appliance. Propose, and be upfront about the limitation:
- **Extract density (°Brix via optical refractometer sensor, or a simple inline conductivity/TDS-style proxy)** as a real-time surrogate for "extractive value" — API defines extractive value (% w/w) as a key QC parameter for kwatha churna; density/Brix correlates with total dissolved extractives and is a widely used industrial proxy in herbal concentrate production.
- **Load-cell-tracked mass loss** during reduction as a cross-check that the ¼-volume reduction endpoint was actually reached (evaporated mass ≈ initial water mass − final dose mass, corrected for absorbed water in spent powder).
- Clearly state in your PPT that **full API-compliance validation (extractive value %, HPTLC marker-compound fingerprint) would be done at the pod-certification stage by AIIA/PCIM&H on the batch/formulation level**, not per-cup — the appliance's job is to *reliably reproduce* a pre-validated process (time/temp/pressure/ratio profile), not to re-certify each cup. This is an important nuance: it matches how the PS frames pod certification ("Pods... are certifiable against the API/AFI by AIIA/PCIM&H") and shows you understand the QC boundary between appliance and pharmacy.

---

## 4. What to build — three deliverables

| Deliverable | Purpose | Detailed doc |
|---|---|---|
| **CAD (mechanical/industrial design)** | Full appliance shape, boiling chamber, pod bay, exploded internal architecture | [structure.md](structure.md) |
| **PCB / electronics** | Sensor suite, control board, power stage, firmware architecture | [pcb.md](pcb.md) |
| **App + backend/website** | Pod profile management, cycle control/monitoring, dose history, clinic/consumer modes | [app_and_website.md](app_and_website.md) |

---

## 5. Reference list (cite these in your PPT's "references" slide)
- PCIM&H, *AFI/2020/KC/1.0 — Formulary Specification of AYUSH Kvātha Cūrṇa* — pcimh.gov.in
- PCIM&H, *API-2/2020/KC/1.0 — Pharmacopoeial Monograph of AYUSH Kvātha Cūrṇa* — ccrum.res.in
- *The Ayurvedic Pharmacopoeia of India*, Part I & Part II (Formulations) — cdn.ayush.gov.in
- All India Institute of Ayurveda (AIIA) — institutional mandate on drug standardization, QC, safety evaluation
- General food-industry reference: vacuum/reduced-pressure evaporation & concentration principles (rotary evaporation, low-temperature vacuum concentration preserving heat-labile actives)

---

## 6. Open questions to resolve with your team before locking the PPT
1. Do we build a **single reference formulation profile** (e.g., a common Dashamoola-type kwatha) for the working prototype, and only *simulate* multi-formulation pod-switching in the app? (Recommended for a hackathon timeline — don't try to physically validate multiple herbs.)
2. Vacuum pump sourcing/cost vs a simpler "surface area + fan" only approach for the first prototype — decide the MVP tier vs the "full vision" tier and present both (MVP now, vacuum-assisted as the funded/production roadmap) if the vacuum BOM is too expensive/complex to get working reliably in the hackathon window.
3. Pod mechanical design: reusable brew-basket + disposable powder sachet (cheaper, easier to prototype) vs fully sealed single-use pod with integrated mesh (closer to the PS's literal wording, harder to prototype fast) — see [structure.md](structure.md) §pod design for the tradeoff table.

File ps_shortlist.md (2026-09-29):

# SIH 2026 shortlisted problem statements

Source: https://sih.gov.in/sih2026PS (pulled 2026-09-24). Site totals: 240 PS (58 hardware, 182 software; 17 hardware themes, 17 software themes). Idea submission deadline for all ten: 30 September 2026. Submitted count is shown as "n/500", so each PS is capped at 500 ideas.

## Summary

| PS | Organization | Category (per site) | Theme | Submitted |
|---|---|---|---|---|
| SIH26007 | Ministry of Steel (NMDC) | Hardware | Smart Automation | 131/500 |
| SIH26010 | Ministry of Rural Development (DoLR) | Hardware | Agriculture, FoodTech & Rural Development | 29/500 |
| SIH26087 | Ministry of Cooperation (NCCT) | Hardware | Smart Education | 13/500 |
| SIH26088 | Ministry of Cooperation (NCCT) | Hardware | Agriculture, FoodTech & Rural Development | 22/500 |
| SIH26232 | Ministry of Food Processing Industries | Hardware | Agriculture, FoodTech & Rural Development | 16/500 |
| SIH26123 | Bharat Electronics Limited | Software | Smart Automation | 25/500 |
| SIH26046 | Ministry of Ayush (AIIA) | Software | MedTech / BioTech / HealthTech | 31/500 |
| SIH26072 | Ministry of Earth Sciences (IMD) | Software | Disaster Management | 10/500 |
| SIH26160 | NTRO | Software | Blockchain & Cybersecurity | 14/500 |
| SIH26163 | NTRO | Software | Smart Automation | 11/500 |

Notes: the YouTube and contact-info fields for every PS just link back to the SIH problem statements page (no per-PS video or contact was published). Dataset links are empty except 26046 (truncated on the site) and 26163.

---

## SIH26007 — Hardware — 131/500
**Title:** Safe and Efficient Operation of Mine Vehicles in Fog and Low-Visibility Conditions in Open Cast Iron Ore Mines
**Organization:** Ministry of Steel | **Department:** NMDC | **Theme:** Smart Automation

**Background:** NMDC Limited is India's largest iron ore producer, at about 53 Million Tonnes Per Annum (MTPA) from three fully mechanized complexes: BIOM-Kirandul and BIOM-Bacheli in Chhattisgarh, and Donimalai in Karnataka. The Bailadila Region alone contributes nearly 37 MTPA. In line with the National Steel Policy, NMDC targets 100 MT capacity by 2030, with about 80 MT expected from the Bailadila Sector.

The Bailadila region has severe monsoon conditions from June to October: heavy rain, strong winds, high humidity, dense clouds and thick fog. Visibility on haul roads, especially in hilltop mining areas, can fall to 3–5 metres. This affects the safe and efficient movement of Heavy Earth Moving Machinery (HEMM), especially ore-carrying dumpers.

**Problem Description:** Dense fog forces operators to slow down or halt to avoid accidents. This increases haul cycle times, cuts fleet productivity and ore evacuation, and raises collision and accident risk. Existing visibility aids and operational controls have limited effectiveness in dense fog. An intelligent, reliable, technology-driven solution is needed for safe, efficient vehicle movement in low visibility, keeping operations and production continuous.

**Expected Solution:** Improve operator situational awareness, assist vehicle guidance and collision avoidance, and support real-time monitoring and decision-making on haul roads in adverse weather. May use:
- AI/ML-based analytics
- Computer vision and thermal imaging
- LiDAR and radar-based sensing
- GPS/DGPS-based vehicle tracking
- Vehicle-to-Vehicle (V2V) and Vehicle-to-Infrastructure (V2I) communication
- Autonomous or driver-assistance systems
- IoT-enabled monitoring systems
- Centralized command and control platforms
- Digital Twin-based operational monitoring

**Expected Outcomes:**
- Improved safety of dumper operations in fog
- Fewer collision risks and accidents
- Better haulage efficiency and shorter cycle times
- Higher fleet utilization and continuity of mining during monsoon
- Lower production losses from low visibility
- Real-time monitoring and decision support for operators and control rooms
- Scalable, deployable solution for large mechanized open-cast mines

---

## SIH26010 — Hardware — 29/500
**Title:** Survey/Resurvey of Rural Agricultural Land in India
**Organization:** Ministry of Rural Development | **Department:** Department of Land Resources (DoLR) | **Theme:** Agriculture, FoodTech & Rural Development

**Background:** Rural land surveys were historically done with chain and tape methods, some dating to the colonial period. Problems that built up: boundary changes from inheritance and informal partition, unrecorded transactions, encroachments and overlapping claims, errors in cadastral maps, mismatch between textual records and spatial maps, no updated mutation records, and inconsistent land classification. These cause long legal disputes, lower agricultural productivity and administrative inefficiency. Land disputes reportedly make up a major share of civil litigation in India.

**Detailed Description:** A comprehensive survey/resurvey programme is needed to establish accurate ownership, update cadastral maps, reduce disputes, enable transparent land governance, support precision agriculture, improve rural planning, enable digital land administration and ensure effective implementation of government schemes. Drone mapping, Differential GPS (DGPS), GIS platforms, satellite imagery, CORS and mobile-based field verification can improve accuracy, speed and transparency.

**Expected Solution:** Technology-driven survey and resurvey for accurate mapping of agricultural parcels using drone-based aerial surveys, Real-Time Kinematic (RTK) GPS and DGPS, GIS-enabled cadastral mapping and geo-referenced parcel identification. Build a unified digital land information system integrating Record of Rights (RoR), mutation records, registration databases, survey maps, ownership history and precise geo-coordinates of parcels, enabling real-time update and verification of ownership.

---

## SIH26087 — Hardware (mode: Software + Hardware) — 13/500
**Title:** AI & LMS-Enabled Cooperative Capacity Building, ERP & Employment Ecosystem
**Organization:** Ministry of Cooperation | **Department:** National Council for Cooperative Training (NCCT) | **Theme:** Smart Education

**Background:** NCCT, through VAMNICOM, RICMs and ICMs, runs large-scale training for cooperative personnel, PACS members, SHGs, dairy cooperatives, farmers and rural youth. Trained rural youth often struggle to reach employment, entrepreneurship support, digital learning and visibility of skill certifications. Existing systems are largely manual or fragmented: duplicated effort, weak trainee tracking, limited learning analytics, poor employment linkage, inefficient programme administration.

**Problem Statement:** Develop an integrated digital ecosystem for cooperative training institutions combining ERP-based training management, e-learning, data analytics, skill development, digital literacy and employment exchange for cooperative stakeholders and rural youth.

**Scope:** A centralized, scalable, web-based platform integrating all major training management activities under NCCT institutions.

**Expected Solution Features:**
- Online programme registration and nomination management
- Participant, institution and trainee profile management
- Interactive multilingual e-learning modules
- Digital attendance through face recognition / QR code
- Timetable, hostel and logistics management
- LMS integration with assessments and certification
- Skill certification repository and verification
- Career counseling chatbot
- Employer and recruiter dashboard
- Mobile-friendly, offline-accessible learning platform
- Centralized database for future programme outreach and monitoring

**Technology Components:** LMS, cloud-based ERP, data analytics, mobile apps, multimedia and interactive learning tools, face recognition / QR. **Proposed mode:** Software + Hardware.

---

## SIH26088 — Hardware (mode: Software + Hardware) — 22/500
**Title:** Multilingual Cooperative Governance & Legal Assistance Chatbot
**Organization:** Ministry of Cooperation | **Department:** NCCT | **Theme:** Agriculture, FoodTech & Rural Development

**Problem Statement:** Cooperative members, farmers and rural stakeholders often lack awareness of cooperative laws, government schemes, PACS services, crop insurance, financial literacy and grievance redressal, because of language barriers and limited access to reliable guidance.

**Objective:** An AI-powered multilingual chatbot giving instant guidance on cooperative governance, legal provisions, schemes and member services.

**Expected Solution Features:**
- Multilingual conversational interface
- Guidance on cooperative laws and by-laws
- Information on Ministry of Cooperation schemes and services
- PMFBY and agricultural support guidance
- Financial literacy assistance
- Cooperative grievance redressal support
- Voice-enabled assistance for rural users
- Integration with mobile and web platforms

**Technology Components:** NLP, AI chatbot frameworks, speech-to-text and text-to-speech, cloud computing. **Proposed mode:** Software + Hardware.

---

## SIH26232 — Hardware — 16/500
**Title:** Low-Cost IoT Blockchain Nodes for Farm-to-Fork Traceability
**Organization:** Ministry of Food Processing Industries (MoFPI) | **Department:** MoFPI | **Theme:** Agriculture, FoodTech & Rural Development

**Background:** Export markets demand strict traceability standards to combat food fraud and track contamination outbreaks. Large enterprises can afford complex cold-chain logging; Small and Medium Enterprises are priced out. Standard data loggers also lose connectivity in remote farm areas, leaving blind spots in supply chain data.

**Description:** An affordable, rugged, tamper-proof hardware device is needed to track ambient environmental data in transit. It must survive harsh agricultural and industrial environments (extreme moisture, dust, vibration) while continuously logging metrics like temperature, humidity and ethylene gas.

**Expected Solution:** A low-power, plug-and-play IoT sensor node with local cryptographic storage to keep data integrity during cellular dropouts, plus energy harvesting (solar or thermal) to extend battery life indefinitely. On reconnecting, it must automatically sync encrypted data to a decentralized ledger using lightweight protocols such as MQTT, preventing unauthorized manipulation of cold-chain logs.

---

## SIH26123 — Software — 25/500
**Title:** Edge-AI Based Distributed Fleet Coordination for Autonomous Mobile Robots (AMRs) in Smart Warehouses
**Organization:** Bharat Electronics Limited | **Department:** Bharat Electronics Limited | **Theme:** Smart Automation

**Background:** Smart warehouses use fleets of AMRs. As fleets grow, relying on a centralized cloud server for path planning causes network latency, Wi-Fi dead-zone vulnerability and single-point-of-failure risk. Robotics is shifting toward decentralized, edge-computing solutions where robots talk to each other directly and decide in real time.

**Description:** Design a decentralized coordination and collision-avoidance framework for a multi-robot fleet (at least 3 AMRs) in a dynamic warehouse. It must run locally on edge hardware (e.g. Raspberry Pi or Jetson Nano onboard each robot) and handle:
1. Decentralized communication: inter-robot messaging of position and intent without a central server.
2. Dynamic multi-agent conflict resolution: resolving deadlocks and avoiding collisions at narrow intersections or choke points in real time.
3. Task allocation and re-routing: automatically reassigning pickup points or changing paths if a robot meets a blocked aisle.

**Expected Solution:** A multi-robot simulation with a decentralized network stack (peer-to-peer protocol sharing localization data locally), multi-agent path planning algorithms for edge hardware, and a lightweight fleet dashboard showing real-time positions and battery status. **Success criteria:** zero inter-robot collisions and at least a 20% reduction in total task completion time versus traditional stop-and-wait when paths overlap.

---

## SIH26046 — Software — 31/500
**Title:** AIIA Clinical Trials Dashboard: a real-time, cloud-based, GCP-compliant Clinical Trial Management System (CTMS) for Ayurveda research, with CDISC/FHIR-interoperable data, role-based KPIs, and integrated ethics, regulatory (CTRI / NDCT Rules 2019) and pharmacovigilance tracking
**Organization:** Ministry of Ayush | **Department:** All India Institute of Ayurveda | **Theme:** MedTech / BioTech / HealthTech

**Background:** AIIA runs a growing portfolio of clinical research in Ayurveda (interventional, observational, multi-centre trials) and, as host of the National Pharmacovigilance Coordination Centre (NPvCC) for ASU&H drugs, anchors nationwide safety surveillance. The compliance framework: mandatory prospective CTRI registration; GCP guidelines for ASU medicine (GCP-ASU) and ICMR National Ethical Guidelines; New Drugs and Clinical Trials Rules 2019 where applicable; Institutional Ethics Committee oversight; timely AE/SAE reporting. Yet study status, recruitment, milestones, data quality and safety signals are tracked across spreadsheets and disconnected tools with no real-time, auditable view, causing delayed decisions, missed reporting timelines and avoidable compliance risk.

**Description:** A real-time, cloud-based CTMS and monitoring dashboard giving AIIA a single, role-based, auditable view of its clinical-research portfolio. It tracks each study across its lifecycle: protocol and Ethics Committee approval, CTRI registration, site activation, screening, enrolment and randomization against target, visit and protocol-deviation compliance, data-query and data-quality status, milestones and timelines, and close-out, surfaced as real-time KPIs with configurable alerts (enrolment lag, ethics approval or CTRI update due, overdue monitoring visit).

Because AIIA hosts the NPvCC, the dashboard integrates pharmacovigilance: it captures and routes ADR/AE/SAE reports against regulatory timelines, coded to MedDRA and WHODrug, and feeds aggregate safety signals to the Data Safety Monitoring Board and leadership. Data must follow CDISC (CDASH, SDTM, ADaM) and HL7 FHIR R4 for interoperability with Electronic Data Capture (EDC), the hospital information system and Ayushman Bharat Digital Mission (ABDM) building blocks, with ALCOA+ data integrity and an immutable, time-stamped audit trail. Access is strictly role-based (Principal Investigator, study coordinator, monitor, Ethics Committee, pharmacovigilance, administration, read-only regulator). It must comply with GCP-ASU, ICMR guidelines, NDCT Rules 2019, CTRI requirements and the Digital Personal Data Protection Act 2023 and 2025 Rules (informed-consent management, data minimisation, encryption, data-resident cloud hosting to ISO/IEC 27001 and CERT-In norms).

**Expected Solution:** A deployable cloud CTMS-and-analytics dashboard with: real-time portfolio view with per-study drill-down; configurable KPIs and alerting; strict role-based access and an immutable ALCOA+ audit trail; CDISC-aligned data models and HL7 FHIR R4 / ABDM interoperability with EDC and the HIS; an integrated pharmacovigilance module (AE/SAE capture, MedDRA/WHODrug coding, regulatory-timeline tracking); CTRI and ethics/regulatory milestone tracking; informed-consent and privacy controls aligned to DPDP; e-signature and data-integrity controls consistent with GCP; export of submission-ready datasets (SDTM / ADaM, Define-XML). Tailored dashboards for Investigators, the Ethics Committee, pharmacovigilance and leadership. The build can be staged: core study-tracking and KPI MVP first, then EDC/FHIR integration and the pharmacovigilance module, then full CDISC export and advanced analytics. Evaluated on data accuracy and integrity, timeliness of safety and regulatory reporting, interoperability conformance, and access-control and audit completeness.

**Dataset link (truncated on the site):** Clinical-trial data is sensitive personal data, so development should use synthetic / de-identified datasets; representative standards and public sources: Clinical Trials Registry – India (ctri.nic.in); CDISC standards and controlled terminology (cdisc.org); HL7 FHIR R4 specification and ABDM buildi[ng blocks…]

---

## SIH26072 — Software — 10/500
**Title:** AIML based Nowcasting of thunderstorm and lightning using atmospheric observation including multiple radars, satellite, lightning and model data
**Organization:** Ministry of Earth Sciences (MoES) | **Department:** India Meteorological Department | **Theme:** Disaster Management

**Description:** The site's description field only repeats the title (no background, scope or expected-solution text was published). No dataset link.

---

## SIH26160 — Software — 14/500
**Title:** AI-Powered IPsec VPN Protocol Analyzer and Security Assessment Framework
**Organization:** National Technical Research Organisation (NTRO) | **Department:** NTRO | **Theme:** Blockchain & Cybersecurity

**Background:** VPNs are fundamental to secure communication over untrusted networks; IPsec is widely used across enterprise, government, military and cloud for confidentiality, integrity and authentication. Its security depends on the chosen algorithms, authentication, key exchange and mode (Tunnel or Transport). Misconfiguration, outdated cipher suites, poor key management or implementation flaws weaken it. Traditional protocol analysis tools give packet-level visibility but need expert interpretation, so intelligent systems that analyze IPsec deployments automatically and give actionable recommendations are needed.

**Description:** Design and develop an AI-driven protocol analysis platform that automatically analyses IPsec VPN deployments under different security configurations. It should inspect captured traffic or live streams, identify protocol characteristics, infer VPN operating modes, evaluate cryptographic configurations and generate an automated security assessment report, without manual packet inspection. Tasks:
a) **VPN testbed generation:** a lab environment establishing IPsec VPNs across configurations: Tunnel/Transport mode, AES-128, AES-256, AES-GCM, AES-CBC + HMAC, different DH groups, Perfect Forward Secrecy on/off, IPv4 and IPv6, and different traffic types (VoIP, WhatsApp, e-mail, web browsing, ICMP, video streaming, etc.).
b) **Traffic capture:** using Wireshark, tcpdump or custom capture utilities; dataset to include IKE negotiation, ESP packets, AH packets (optional) and normal communication.
c) **AI-based protocol identification:** automatically identify IPsec protocol, IKE version, tunnel/transport mode, encryption algorithm, authentication algorithm, key exchange method, Security Association characteristics, and predict the type of traffic inside ESP-IPsec.
d) **Security assessment:** evaluate cryptographic strength, configuration compliance, SA parameters, key lifetime, replay protection, forward secrecy configuration, cipher suite strength and metadata exposure.
e) **Output:** a comprehensive security score, traffic analysis and metadata inference; auto-generated Executive Report and Technical Report, Risk Score, Threat Matrix and AI Confidence Score.

**Expected Solution / Deliverables:** working software prototype, AI classification engine, interactive dashboard, security assessment report, demonstration video, technical documentation, and the dataset used for training/testing.

---

## SIH26163 — Software — 11/500
**Title:** Security Assessment of the World Monitor application
**Organization:** National Technical Research Organisation (NTRO) | **Department:** NTRO | **Theme:** Smart Automation

**Background:** World Monitor is a web/mobile platform with real-time monitoring, analytics and reporting; it handles user authentication, data visualization, API communication and role-based access. As a security analyst, evaluate its security posture and find vulnerabilities that could compromise confidentiality, integrity or availability.

**Description:** Conduct an authorized security assessment to: (1) identify vulnerabilities; (2) assess the impact of each; (3) demonstrate proof-of-concept exploitation in a controlled environment; (4) recommend remediation.

**Scope:** authentication and session management; authorization and access control; input validation and data handling; API security; client-side security controls; secure communication mechanisms; data storage and privacy protections.

**Success criteria:** at least one valid vulnerability identified and documented; evidence supporting it; risk and impact clearly explained; practical mitigation strategies provided.

**Deliverables (per vulnerability):** title, description, affected component, severity rating (e.g. CVSS), steps to reproduce, safe proof of concept, business impact assessment, remediation recommendations.

**Constraints:** test only authorized systems; no actions affecting production users or data; exploitation limited to proof-of-concept validation; comply with applicable laws, policies and ethical hacking guidelines.

**Dataset / links from the site:** App: https://www.worldmonitor.app | Source code: https://github.com/koala73/worldmonitor

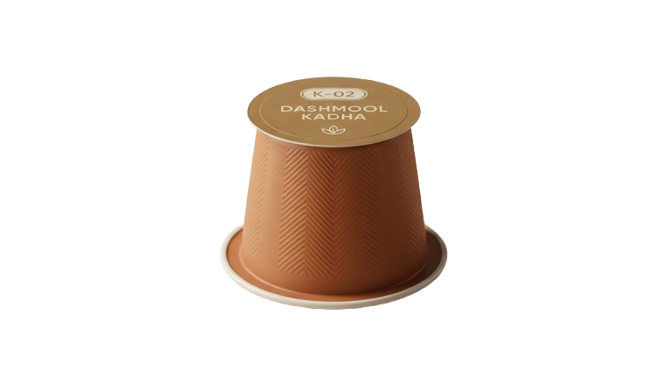
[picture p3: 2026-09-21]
app/assets/pod_k02.png

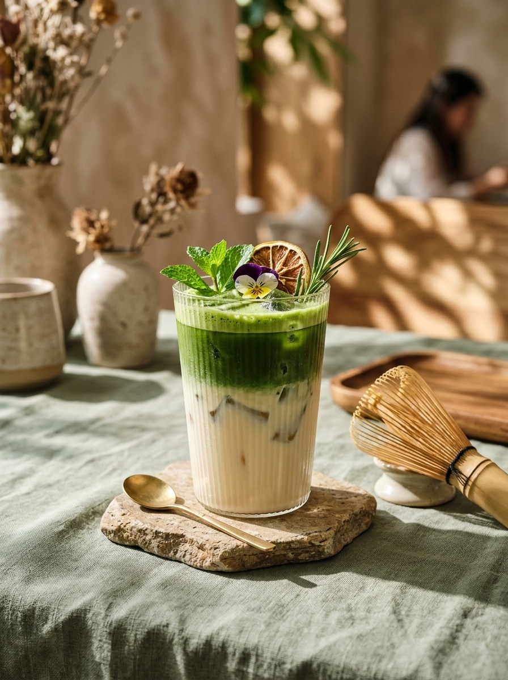
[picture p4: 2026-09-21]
website/assets/hero_drink.jpg

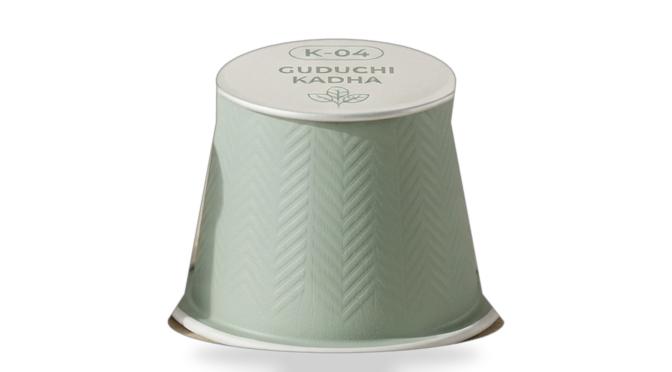
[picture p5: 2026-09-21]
app/assets/pod_k04.png

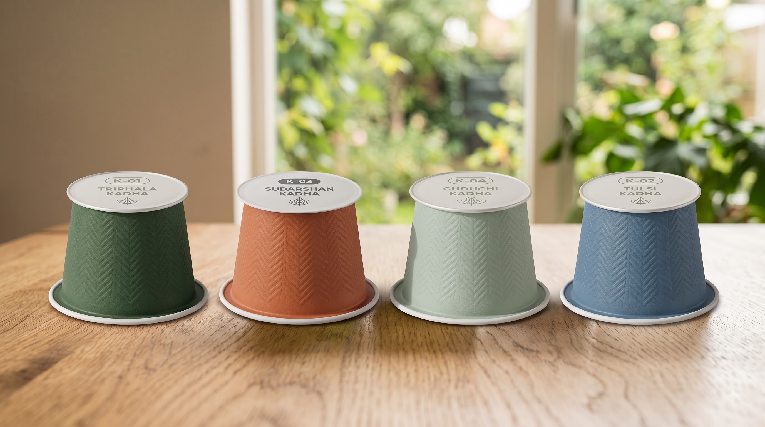
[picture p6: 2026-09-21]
app/assets/hero_seed_jars.jpeg

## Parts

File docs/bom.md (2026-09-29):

# Bill of materials

Source: `blehpcb/BOM.csv` (46 numbered line items). `blehpcb/` is gitignored, so this file is the copy that reaches the remote.

| # | Category | Component | Ref | Value / description | Qty | Cost (INR) |
|---|---|---|---|---|---|---|
| 1 | Microcontroller | ESP32 DevKit V1 (38-pin) | U1 | Dual-core 240MHz, WiFi + BLE, 38-Pin Module | 1 | 350 |
| 2 | Sensors | DS18B20 Temp Probe | J1 | Waterproof stainless digital temperature sensor (1-Wire) | 1 | 110 |
| 3 | Sensors | HX711 ADC Module | U2 | 24-bit ADC load cell amplifier module | 1 | 90 |
| 4 | Sensors | 1kg Load Cell | J2 | Straight-bar strain gauge load cell (E+, E-, A+, A-) | 1 | 180 |
| 5 | Sensors | MFRC522 RFID/NFC Reader | U3 | 13.56MHz SPI RFID reader module for pod formulation ID | 1 | 140 |
| 6 | Sensors | BMP280 Barometric Sensor | U4 | Digital pressure & ambient temperature sensor (I2C) | 1 | 120 |
| 7 | Sensors | Analog TDS Sensor Module | J3 | Water quality / total dissolved solids concentration sensor | 1 | 190 |
| 8 | Sensors | 10k NTC Thermistor | J4 | 10k ohm NTC temperature sensor probe (enclosure monitoring) | 1 | 15 |
| 9 | Display & UI | SSD1306 OLED Display | U5 | 128x64 monochrome graphic display (0.96 inch, I2C) | 1 | 180 |
| 10 | Display & UI | 5mm LED Red | D1 | Red status LED (Heating active) | 1 | 2 |
| 11 | Display & UI | 5mm LED Amber | D2 | Amber status LED (Soak / Reduction phase) | 1 | 2 |
| 12 | Display & UI | 5mm LED Green | D3 | Green status LED (Decoction Ready / Safe) | 1 | 2 |
| 13 | Display & UI | 5mm LED Blue | D4 | Blue status LED (Water fill / Dispense / BLE) | 1 | 2 |
| 14 | Display & UI | Passive Piezo Buzzer | BZ1 | Audible buzzer for cycle start, completion and error alarms | 1 | 18 |
| 15 | Input Switches | Lid Interlock Microswitch | J5 | Lever micro limit switch for lid position sense | 1 | 20 |
| 16 | Input Switches | Boil-Over Detect Switch | J6 | Chamber rim float / microswitch for anti-boilover safety | 1 | 20 |
| 17 | Input Switches | Water Fill-Level Switch | J7 | Water reservoir / chamber level float limit switch | 1 | 25 |
| 18 | GPIO Expander | PCF8574 I2C Expander #1 | U6 | 8-bit I2C GPIO expander module (Address 0x20, Relays 2-7 + Buzzer) | 1 | 75 |
| 19 | GPIO Expander | PCF8574 I2C Expander #2 | U7 | 8-bit I2C GPIO expander module (Address 0x21, Status LEDs) | 1 | 75 |
| 20 | Actuators | 12V Silicone Heater Pad | TB3 | 12V flexible food-safe silicone heating element (30-50W) | 1 | 350 |
| 21 | Actuators | 12V Mini Vacuum Pump | TB4 | 12V DC mini diaphragm vacuum pump for reduced-pressure boil | 1 | 420 |
| 22 | Actuators | 12V Recirculation Pump | TB5 | 12V DC mini diaphragm/peristaltic liquid pump | 1 | 240 |
| 23 | Actuators | 12V Dispense Pump | TB6 | 12V DC mini food-grade liquid transfer pump | 1 | 240 |
| 24 | Actuators | 12V Inlet Solenoid Valve | TB7 | 12V DC normally-closed water inlet valve | 1 | 180 |
| 25 | Actuators | 12V Solenoid Lid Lock | TB8 | 12V DC electronic solenoid catch lock mechanism | 1 | 190 |
| 26 | Actuators | 12V Brushless Fan 40mm | TB9 | 12V DC 40mm brushless cooling / steam evacuation fan | 1 | 95 |
| 27 | Actuators | SG90 Micro Servo 9g | J8 | 5V 9g micro servo motor for herbal pod ejection mechanism | 1 | 110 |
| 28 | Actuator Drivers | 5V 1-Ch Relay Module | K1..K7 | 5V opto-isolated single-channel relay modules (7 modules total) | 7 | 350 |
| 29 | Power Supply | 220V AC to 12V 5A Supply | PS1 | Enclosed switching power supply module (12V DC 5A, 60W) | 1 | 380 |
| 30 | Power Supply | LM2596 DC-DC Buck Module | U8 | Adjustable step-down regulator module, calibrated to 5.0V output | 1 | 65 |
| 31 | Safety & Protection | 5A Inline / PCB Fuse | F1 | 5x20mm fast-acting glass cartridge fuse with holder | 1 | 20 |
| 32 | Safety & Protection | Bimetallic Thermal Fuse | F2 | 95-100°C normally-closed thermal cutoff (hardware cutoff) | 1 | 40 |
| 33 | Safety & Protection | Lid Interlock Contact Block | TB10 | Hardware series interlock cutout terminal block | 1 | 15 |
| 34 | Passive Components | Resistor 4.7k ohm 1/4W | R1, R6, R7 | 1-Wire & I2C SDA/SCL pull-up resistors | 3 | 3 |
| 35 | Passive Components | Resistor 10k ohm 1/4W | R2, R3, R4, R5 | NTC divider & limit switch pull-up resistors | 4 | 4 |
| 36 | Passive Components | Resistor 330 ohm 1/4W | R8, R9, R10, R11 | Status LED current limiting resistors | 4 | 4 |
| 37 | Passive Components | Ceramic Capacitor 100nF | C1..C10 | Decoupling (ESP32, HX711, RFID, BMP, TDS, Expanders) & Debounce | 10 | 15 |
| 38 | Passive Components | Electrolytic Cap 100uF | C12, C13 | Buck converter input (25V) and output (10V) filtering | 2 | 8 |
| 39 | Passive Components | Electrolytic Cap 470uF 16V | C11 | Bulk decoupling on main 12V high-current rail | 1 | 10 |
| 40 | Connectors & Headers | JST-XH 2-Pin Connector | J4, J5, J6, J7 | 2.50mm vertical JST-XH headers for switches and NTC | 4 | 16 |
| 41 | Connectors & Headers | JST-XH 3-Pin Connector | J1, J3, J8 | 2.50mm vertical JST-XH headers for DS18B20, TDS, Servo | 3 | 15 |
| 42 | Connectors & Headers | JST-XH 4-Pin Connector | J2 | 2.50mm vertical JST-XH header for Load Cell | 1 | 6 |
| 43 | Connectors & Headers | 10-Pin Inter-Board Header | J9, J_PWR_LINK | 2.54mm pin header for inter-board 5V/3V3/GND/PID link | 2 | 20 |
| 44 | Connectors & Headers | 6-Pin Relay Signal Header | J10, J_RELAY_CTRL | 2.54mm pin header for 6x relay control bus | 2 | 16 |
| 45 | Connectors & Headers | Screw Terminal Block 2P | TB1..TB10 | 5.08mm 2-pin screw terminal blocks for 12V power & actuators | 10 | 120 |
| 46 | Hardware | M3 Mounting Hardware | H1..H4 (x2 boards) | M3 PCB standoffs and stainless screws | 8 | 40 |

Sum of the cost column: **INR 4,588** (about US$55).
Sum of quantity x cost: INR 8,335.

## Reading the total

The CSV ends with its own row, "TOTAL ESTIMATED BOM COST (INR): 4588", which equals the plain sum of the cost column. That matches reading each figure as the cost of the whole line (item 46, eight M3 fasteners for INR 40, is consistent with that). If the figures were unit prices the bill would be INR 8,335 instead. Spot-check two or three lines against a supplier listing before quoting a price outside the team.

## Notes

* The README's earlier table used slightly different prices (for example ESP32 at INR 420 versus 350 here); the CSV is the more detailed source.
* Not included: enclosure, SS304 boiling chamber, load-cell mounting, tubing, fittings, pod tooling, and the PCB fabrication cost.
* Sourcing categories in the CSV point to hobby-electronics suppliers; food-contact parts (pumps, tubing, chamber) need food-grade certification before any real use.

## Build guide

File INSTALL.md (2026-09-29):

# iKwath: Installation and Run Guide

How to run or open every part of the repository. Nothing here needs a build step except the optional PCB regeneration.

## 0. What you can run

| Part | Needs | Effort |
|---|---|---|
| `website/` interactive app | any browser, optionally Python 3 or Node | one command |
| `app/` product site | any browser, optionally Python 3 | one command |
| `pcb/` KiCad project | KiCad 8 or newer | open the project |
| `ino/` ESP32 firmware | Arduino IDE or arduino-cli with the ESP32 board package | optional |
| `blehpcb/` generators (local only) | KiCad's bundled Python | optional |

There is no backend to start. The ESP32 firmware is in `ino/` (section 3); it has not yet run on the appliance.

## 1. Interactive app (`website/`)

```bash
cd website
python3 -m http.server 8080
```

Open http://localhost:8080. Alternatives: `npx serve .` inside `website/`, or open `website/index.html` directly (macOS: `open website/index.html`).

What to try: let the logo intro finish, sign in with the demo form, tap the active pod card to switch between Triphala, Ayush and Dashamoola, start the extraction and watch the five stages, the temperature curve pinned to the 85 to 90 C band and the 400 to 100 mL gauge. The camera icon opens a pod-scanner viewfinder simulation. The profile screen shows placeholder account data.

## 2. Product site (`app/`)

```bash
cd app
python3 -m http.server 8123
```

Open http://localhost:8123. The page loads product images and `assets/herb_opt.mp4`; a slow first load is the video.

`app/_assets_backup/` holds unused media. Restore it with `./_assets_backup/RESTORE_ALL.sh` from `app/` if you need the originals.

## 3. ESP32 firmware (`ino/`)

1. Install the ESP32 board package in the Arduino IDE.
2. Install the libraries listed in [ino/README.md](ino/README.md).
3. Open `ino/ikwath_firmware/ikwath_firmware.ino`, choose ESP32 Dev Module, upload, and open the serial monitor at 115200 baud.
4. Tare and calibrate the load cell (`t`, then `cal <grams>`) before any test. Do not connect the heater or mains until the bench checks in the README pass.

The sketch is a first draft and has not been run on hardware.

## 4. PCB project (`pcb/`)

1. Install KiCad 8 or newer.
2. Open `pcb/ikwath.kicad_pro` (the `.kicad_pcb` and `.kicad_sch` open from the project window).
3. Run Inspect, Design Rules Checker and Electrical Rules Checker to see the current state; expected results are described in [docs/pcb-status.md](docs/pcb-status.md).

`pcb/.history/` is a KiCad local-history folder and is not part of the design.

## 5. Local PCB work (`blehpcb/`, gitignored)

These files exist only on the author's machine. To regenerate the scripted boards:

```bash
KPY="/Applications/KiCad/KiCad.app/Contents/Frameworks/Python.framework/Versions/Current/bin/python3"
$KPY blehpcb/pcbreal/control-board/build.py
$KPY blehpcb/pcbreal/power-board/build.py
```

Then re-run rule checks with `kicad-cli` (paths vary by KiCad version):

```bash
kicad-cli pcb drc --output drc.rpt blehpcb/pcbreal/control-board/control-board.kicad_pcb
```

The scripts place and connect components; some boards still have unrouted nets afterwards (see [docs/pcb-status.md](docs/pcb-status.md)).

## 6. Troubleshooting

| Symptom | Fix |
|---|---|
| Page loads but images are missing | Serve over HTTP from inside `website/` or `app/`, not from another folder |
| Port already in use | Pick another port, for example `python3 -m http.server 8090` |
| KiCad reports missing footprints | Some footprints are custom or renamed; assign library footprints in the Footprint Assignment tool |
| `.claude/launch.json` points to `landwebsite` | That folder does not exist; use `app` or `website` (see CHANGELOG) |

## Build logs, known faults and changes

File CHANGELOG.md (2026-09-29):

# iKwath Changelog

All notable changes are documented here. Format follows [Keep a Changelog](https://keepachangelog.com/en/1.0.0/); versions follow [Semantic Versioning](https://semver.org/spec/v2.0.0.html).

Repository history: three commits on 2026-09-21 (`238240f`, `80da5cf`, `7036a7b`). Version 0.4.0 below is the documentation pass applied after them and is the next push; see [PUSH_LOG.md](PUSH_LOG.md).

---

## [0.4.0] - 2026-09-30

### Added
- `models/ikwath_process_model.ipynb`: vacuum boiling point, energy budget, heat-up and reduction simulation, load-cell endpoint noise study, pod tag encode/decode. Its energy balance flags that the 50 W heater cannot meet the cycle-time target.
- `ino/`: ESP32 firmware sketch (`ikwath_firmware`) implementing the brew cycle, safety checks, PID heater control, load-cell endpoint, NFC pod profiles, serial commands and an optional HTTP interface, plus `ino/README.md`. First draft, not yet run on hardware.
- `INSTALL.md`, `CHANGELOG.md`, `PUSH_LOG.md`, `SIH26048_PROJECT_REPORT.md`.
- `docs/` engineering set: pod and extraction, control sequence, pinout and buses, safety system, PCB status, bill of materials, app and cloud, limitations, judge Q&A.

### Changed
- `README.md` restructured: problem, solution, physics, working principle, dual-PCB architecture, safety, applications, BOM, a Built-versus-Designed status table, documentation map. Repository layout now matches the folders that actually exist.

### Corrected
- Removed the unverified "zero-error" rule-check claim; the actual state of each board iteration is recorded in `docs/pcb-status.md`.
- The README layout listed a `landwebsite/` folder that does not exist and omitted `app/`, `pcb/` and `docs/`; fixed.
- The BOM total of INR 4,588 is now stated with its assumption (cost column read as line totals; INR 8,335 if the figures were unit prices) and the item count corrected to 46.
- States plainly that the firmware is an untested draft and that the web app's extraction is a simulation.

### Noted, not changed
- `.claude/launch.json` still targets a `landwebsite` folder.
- `pcb/.history/` contains a nested git repository and an unrelated KiCad file name (`AGRITHON_2.0.kicad_pcb`).
- `blehpcb/` and `blehread/` are gitignored and therefore not on the remote.

---

## [0.3.0] - 2026-09-21

### Added
- Final KiCad PCB design files and schematics (`pcb/`): project, schematic, PCB, local-history cache. Commit `7036a7b`.

---

## [0.2.0] - 2026-09-21

### Added
- `website/`: interactive brew-simulator web app (HTML, CSS, JavaScript) with manifest and brand assets.
- `app/`: single-page product site with product photography, hero video and an asset backup with restore script.
- `.gitignore` and a Claude launch configuration. Commit `80da5cf`.

---

## [0.1.0] - 2026-09-21

### Added
- Initial README: problem context, Kwatha pharmacopoeial background, extraction physics, pod architecture, fluidics, dual-PCB architecture, safety system, control flow, application and IoT design, BOM, standards. Commit `238240f`.

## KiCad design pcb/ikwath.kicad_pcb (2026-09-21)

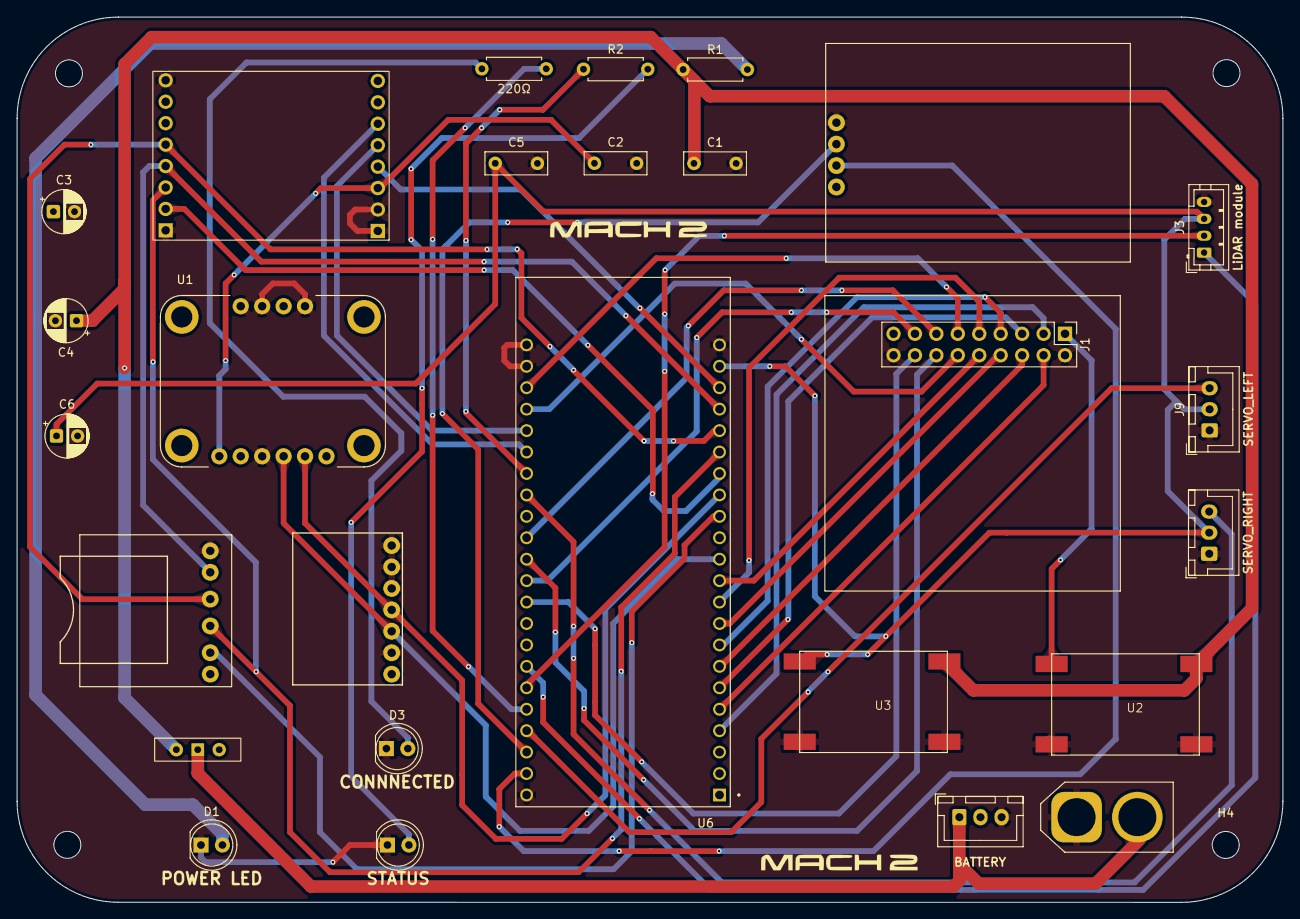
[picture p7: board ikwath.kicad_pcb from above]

Board: 2 copper layers, 150.0 x 104.9 mm, 31 parts (0 on the bottom side), 40 nets.

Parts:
220Ω: 220Ω; R_Axial_DIN0207_L6.3mm_D2.5mm_P7.62mm_Horizontal
C1, C2, C5: 0.1µF; C_Rect_L7.2mm_W2.5mm_P5.00mm_FKS2_FKP2_MKS2_MKP2
C3, C6: 220; CP_Radial_D5.0mm_P2.50mm
C4: 470; CP_Radial_D5.0mm_P2.50mm
D1: POWER LED; LED_D5.0mm
D2: STATUS; LED_D5.0mm
D3: CONNNECTED; LED_D5.0mm
GPS1: NEO_GPS
H1, H2, H4, H6: MountingHole; MountingHole_3.2mm_M3_ISO7380
J1: CAMERA MODULE; PinHeader_2x09_P2.54mm_Vertical
J2: BATTERY; JST_XH_B3B-XH-A_1x03_P2.50mm_Vertical
J3: LiDAR module; JST_PH_B4B-PH-K_1x04_P2.00mm_Vertical
J5: XT-60; AMASS_XT60-M_1x02_P7.20mm_Vertical
J9: SERVO_LEFT; JST_XH_B3B-XH-A_1x03_P2.50mm_Vertical
J11: SERVO_RIGHT; JST_XH_B3B-XH-A_1x03_P2.50mm_Vertical
R1: 3.3KΩ; R_Axial_DIN0207_L6.3mm_D2.5mm_P7.62mm_Horizontal
R2: 220Ω; R_Axial_DIN0207_L6.3mm_D2.5mm_P7.62mm_Horizontal
SDMODULE1: sd_card_module
SW1: SW_Wuerth_450301014042; SW_Slide-03_Wuerth-WS-SLTV_10x2.5x6.4_P2.54mm
U1: BNO055; MODULE_2472
U2, U3: LM2596_buck_conv
U5: LORA_MODULE; SX1278 LoRa Module
U6: ESP32-S3-DEVKITC-1U-N8R2; XCVR_ESP32-S3-DEVKITC-1U-N8R2
m1: MS5611; MS5611F

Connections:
3.3V: C2.1, C3.1, GPS1.3V3, J1.1, SDMODULE1.3V3, U1.1 (VIN), U2.3 (VOUT+), U5.16 (VCC), m1.3.3V
5V: C5.1, C6.1, J3.3, J9.2, J11.2, U3.3 (VOUT+), U6.J1_21 (5V0)
GND: C1.2, C2.2, C3.2, C4.2, C5.2, C6.2, D1.1 (K), D2.1 (K), D3.1 (K), GPS1.GND, J1.2, J1.18, J2.3, J3.4, J5.1, J9.1, J11.1, SDMODULE1.GND, U1.3 (GND), U1.7 (ADR), U1.9 (PS1), U1.10 (PS0), U2.2 (VIN-), U2.4 (VOUT-), U3.2 (VIN-), U3.4 (VOUT-), U5.1 (GND), U5.13 (GND), U5.14 (GND), U5.15 (GND), U6.J1_22 (GND), U6.J3_1 (GND), U6.J3_21 (GND), U6.J3_22 (GND), m1.CSB, m1.GND, m1.PS, m1.SDO
GPIO1: J9.3, U6.J3_4 (GPIO1)
GPIO2: 220Ω.1, U6.J3_5 (GPIO2)
GPIO4: J1.3, U6.J1_4 (GPIO4)
GPIO5: J1.4, U6.J1_5 (GPIO5)
GPIO6: J1.5, U6.J1_6 (GPIO6)
GPIO7: J1.6, U6.J1_7 (GPIO7)
GPIO8: U1.4 (SDA), U6.J1_12 (GPIO8), m1.SCL
GPIO9: U1.5 (SCL), U6.J1_15 (GPIO9), m1.SDA
GPIO10: U5.5 (NSS), U6.J1_16 (GPIO10)
GPIO11: SDMODULE1.MOSI, U5.3 (MOSI), U6.J1_17 (GPIO11)
GPIO12: SDMODULE1.CLK, U5.4 (SCK), U6.J1_18 (GPIO12)
GPIO13: SDMODULE1.MISO, U5.2 (MISO), U6.J1_19 (GPIO13)
GPIO14: U5.6 (RESET), U6.J1_20 (GPIO14)
GPIO15: J1.7, U6.J1_8 (GPIO15)
GPIO16: J1.8, U6.J1_9 (GPIO16)
GPIO17: J1.9, U6.J1_10 (GPIO17)
GPIO18: J1.10, U6.J1_11 (GPIO18)
GPIO19: J1.11, U6.J3_20 (USB_D-/GPIO19)
GPIO20: J1.12, U6.J3_19 (USB_D+/GPIO20)
GPIO21: U5.7 (DI0O), U6.J3_18 (GPIO21)
GPIO35: J1.13, U6.J3_13 (GPIO35)
GPIO36: J1.14, U6.J3_12 (GPIO36)
GPIO37: J1.15, U6.J3_11 (GPIO37)
GPIO38: J1.16, U6.J3_10 (GPIO38)
GPIO41: J3.1, U6.J3_7 (MTDI/GPIO41)
GPIO42: J3.2, U6.J3_6 (MTMS/GPIO42)
GPIO43: GPS1.RX, U6.J3_2 (U0TXD/GPIO43)
GPIO44: GPS1.TX, U6.J3_3 (U0RXD/GPIO44)
GPIO45: J11.3, U6.J3_15 (GPIO45)
GPIO46: SDMODULE1.CS, U6.J1_14 (GPIO46)
GPIO47: U5.8 (DIO1), U6.J3_17 (GPIO47)
GPIO48: R2.1, U6.J3_16 (GPIO48)
unnamed: D1.2 (A), R1.2
unnamed: D2.2 (A), R2.2
unnamed: 220Ω.2, D3.2 (A)
unnamed: J2.1, J5.2, SW1.1 (B)
VIN: C1.1, C4.1, R1.1, SW1.2 (C), U2.1 (VIN+), U3.1 (VIN+)

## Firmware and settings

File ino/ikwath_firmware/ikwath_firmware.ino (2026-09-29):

/*
 * iKwath control firmware (ESP32 DevKit V1)
 *
 * Runs the brew cycle described in docs/control-sequence.md:
 *   IDLE -> READY -> FILL -> SOAK -> BOIL -> VENT -> DISPENSE -> EJECT -> DONE
 * with FAULT reachable from every powered state.
 *
 * The heater is also protected by hardware in series with it (lid interlock,
 * bimetallic cutoff, fuse); the checks here are an additional software layer.
 *
 * Serial commands (115200 baud), one per line:
 *   s        start the cycle (pod must be read and lid closed)
 *   x        abort and return to idle
 *   r        clear a fault (only when the cause is gone)
 *   t        tare the load cell
 *   cal <g>  calibrate with a known mass (in grams) on the scale; stored in flash
 *   h        help
 *
 * Status: first draft written from the project specification. It has not been
 * compiled or run on the physical appliance; expect first-build fixes, and measure
 * every CALIBRATE value in config.h before a powered test.
 */

#include <Arduino.h>
#include <Wire.h>
#include <SPI.h>
#include <math.h>
#include <Preferences.h>
#include <OneWire.h>
#include <DallasTemperature.h>
#include <Adafruit_GFX.h>
#include <Adafruit_SSD1306.h>
#include <Adafruit_BMP280.h>
#include <MFRC522.h>
#include <ESP32Servo.h>

#include "pins.h"
#include "config.h"
#include "pid.h"
#include "hx711_lite.h"
#include "profile.h"

#if ENABLE_WIFI
#include <WiFi.h>
#include <WebServer.h>
#endif

// ------------------------------------------------------------------ devices
OneWire            oneWire(PIN_DS18B20);
DallasTemperature  liquidProbe(&oneWire);
Adafruit_SSD1306   oled(128, 64, &Wire, -1);
Adafruit_BMP280    bmp(&Wire);
MFRC522            nfc(PIN_NFC_SS, PIN_NFC_RST);
Servo              ejector;
Hx711Lite          scale(PIN_HX711_DT, PIN_HX711_SCK);
Preferences        prefs;
Pid                heaterPid(PID_KP, PID_KI, PID_KD);

// ------------------------------------------------------------------ state
enum State : uint8_t { S_IDLE, S_READY, S_FILL, S_SOAK, S_BOIL, S_VENT, S_DISPENSE, S_EJECT, S_DONE, S_FAULT };
const char *STATE_NAMES[] = { "IDLE", "READY", "FILL", "SOAK", "BOIL", "VENT", "DISPENSE", "EJECT", "DONE", "FAULT" };

State       state = S_IDLE;
uint32_t    stateSince = 0;
String      faultReason = "";
bool        oledOk = false, bmpOk = false;

BrewProfile profile;
bool        podReady = false;

// live readings
float   liquidC = NAN;
float   chamberKpa = NAN;
float   enclosureC = NAN;
float   massG = NAN;          // grams above tare
float   tdsPpm = 0.0f;
bool    lidClosed = false, boilOver = false, waterPresent = false;

// scale
double  tareRaw = 0.0;
float   countsPerG = HX711_COUNTS_PER_G;
bool    scaleOk = false;

// cycle bookkeeping
float   massBase = 0.0f;       // mass before filling
float   massAtBoilStart = 0.0f;
float   massBeforeDispense = 0.0f;
float   evaporatedG = 0.0f;
float   heaterDuty = 0.0f;
bool    vacuumPumpOn = false;
bool    startRequested = false;

// output shadows
uint8_t pcfRelays = 0xFF;      // relay bits: 1 = off when active-low
uint8_t pcfLeds   = 0xFF;
uint32_t heaterWindowStart = 0;
bool     heaterPinOn = false;

uint32_t lastSensor = 0, lastTelemetry = 0, lastDisplay = 0, lastPid = 0;
uint32_t cycleStart = 0;

#if ENABLE_WIFI
WebServer server(80);
#endif

// ------------------------------------------------------------------ helpers
void setState(State s) {
  state = s;
  stateSince = millis();
  Serial.printf("{\"event\":\"state\",\"state\":\"%s\"}\n", STATE_NAMES[s]);
}

void pcfWrite(uint8_t addr, uint8_t value) {
  Wire.beginTransmission(addr);
  Wire.write(value);
  Wire.endTransmission();
}

void relaySet(uint8_t bit, bool on) {
  bool level = RELAY_ACTIVE_LOW ? !on : on;
  if (level) pcfRelays |= (1 << bit); else pcfRelays &= ~(1 << bit);
  pcfWrite(ADDR_PCF_RELAYS, pcfRelays);
}

void buzzer(bool on) {   // buzzer bit is active high
  if (on) pcfRelays |= (1 << PCF_BUZZER); else pcfRelays &= ~(1 << PCF_BUZZER);
  pcfWrite(ADDR_PCF_RELAYS, pcfRelays);
}

void ledSet(uint8_t bit, bool on) {
  bool level = LED_ACTIVE_LOW ? !on : on;
  if (level) pcfLeds |= (1 << bit); else pcfLeds &= ~(1 << bit);
}

void ledsShow() { pcfWrite(ADDR_PCF_LEDS, pcfLeds); }

void heaterPin(bool on) {
  heaterPinOn = on;
  bool level = RELAY_ACTIVE_LOW ? !on : on;
  digitalWrite(PIN_HEATER, level ? HIGH : LOW);
}

void heaterOff() { heaterDuty = 0.0f; heaterPid.reset(); heaterPin(false); }

// Everything that can hurt anyone goes off. Lid lock is released so the pod can be removed.
void allOutputsOff() {
  heaterOff();
  pcfRelays = RELAY_ACTIVE_LOW ? 0xFF : 0x00;   // all relays off
  pcfRelays &= ~(1 << PCF_BUZZER);
  pcfWrite(ADDR_PCF_RELAYS, pcfRelays);
  vacuumPumpOn = false;
}

void fault(const String &why) {
  if (state == S_FAULT) return;
  allOutputsOff();
  faultReason = why;
  Serial.printf("{\"event\":\"fault\",\"reason\":\"%s\"}\n", why.c_str());
  setState(S_FAULT);
}

// ------------------------------------------------------------------ sensors
float readEnclosureC() {
  int raw = analogRead(PIN_NTC);
  if (raw <= 10 || raw >= 4085) return NAN;                  // open or shorted
  float r = NTC_R_FIXED * raw / (4095.0f - raw);             // NTC to ground
  float t = 1.0f / (1.0f / 298.15f + logf(r / NTC_R25) / NTC_BETA) - 273.15f;
  return t;
}

float readTdsPpm(float tempC) {
  // Standard analog-TDS conversion with linear temperature compensation.
  float v = analogRead(PIN_TDS) * 3.3f / 4095.0f;
  float comp = 1.0f + 0.02f * ((isnan(tempC) ? 25.0f : tempC) - 25.0f);
  float vc = v / comp;
  float ppm = (133.42f * vc * vc * vc - 255.86f * vc * vc + 857.39f * vc) * 0.5f;
  return ppm < 0 ? 0 : ppm;
}

bool tareScale() {
  double avg;
  if (!scale.readAverage(10, avg)) return false;
  tareRaw = avg;
  return true;
}

void readScale() {
  double avg;
  if (scale.readAverage(3, avg)) {
    massG = (float)((avg - tareRaw) / countsPerG);
    scaleOk = true;
  } else {
    scaleOk = false;
  }
}

void readSensors() {
  liquidProbe.requestTemperatures();
  float t = liquidProbe.getTempCByIndex(0);
  liquidC = (t == DEVICE_DISCONNECTED_C || t < -20.0f || t > 125.0f) ? NAN : t;
  if (bmpOk) chamberKpa = bmp.readPressure() / 1000.0f;
  enclosureC = readEnclosureC();
  tdsPpm = readTdsPpm(liquidC);
  lidClosed    = (digitalRead(PIN_LID) == LOW);        // switch closes to ground when lid is latched
  boilOver     = (digitalRead(PIN_BOILOVER) == LOW);   // sensor pulls low when foam is detected
  waterPresent = (digitalRead(PIN_LEVEL) == LOW);      // float switch closes when tank has water
  readScale();
}

// ------------------------------------------------------------------ NFC
void pollPod() {
  if (state != S_IDLE && state != S_READY) return;
  if (!nfc.PICC_IsNewCardPresent() || !nfc.PICC_ReadCardSerial()) return;

  uint8_t buf[18];
  uint8_t size = sizeof(buf);
  BrewProfile p;
  bool ok = false;
  if (nfc.MIFARE_Read(4, buf, &size) == MFRC522::STATUS_OK) ok = decodeProfile(buf, p);
  nfc.PICC_HaltA();

  profile = ok ? p : BrewProfile();       // default profile if the tag is blank or invalid
  podReady = true;
  Serial.printf("{\"event\":\"pod\",\"from_tag\":%s,\"water_ml\":%u,\"setpoint_c\":%.1f,\"evap_g\":%.0f,\"soak_s\":%u}\n",
                profile.fromTag ? "true" : "false", profile.waterMl, profile.setpointC,
                profile.targetEvapG, profile.presoakS);
  if (state == S_IDLE) setState(S_READY);
}

// ------------------------------------------------------------------ safety
// Stops the cycle (via fault) when a limit is crossed; runs on every sensor refresh.
void safetyCheck() {
  if (state == S_IDLE || state == S_READY || state == S_DONE || state == S_FAULT) return;

  bool heating = (state == S_SOAK || state == S_BOIL);
  if (!lidClosed && state != S_EJECT)                     { fault("lid opened during cycle"); return; }
  if (isnan(liquidC))                                     { fault("liquid temperature sensor invalid"); return; }
  if (liquidC >= LIQUID_TRIP_C)                           { fault("liquid over-temperature"); return; }
  if (!isnan(enclosureC) && enclosureC >= ENCLOSURE_TRIP_C) { fault("enclosure over-temperature"); return; }
  if (!scaleOk)                                           { fault("load cell not responding"); return; }
  if (heating && boilOver)                                { fault("boil-over detected"); return; }
  if (millis() - cycleStart > MAX_BOIL_MS + 10UL * 60UL * 1000UL) { fault("maximum cycle time exceeded"); return; }
}

// ------------------------------------------------------------------ control
void serviceHeater(float setpointC) {
  uint32_t now = millis();
  float dt = (now - lastPid) / 1000.0f;
  if (dt >= 0.5f) {                              // PID update at 2 Hz
    heaterDuty = heaterPid.update(setpointC, liquidC, dt);
    lastPid = now;
  }
  // Time-proportional output across a fixed window (relay-friendly).
  if (now - heaterWindowStart >= HEATER_WINDOW_MS) heaterWindowStart = now;
  bool on = (now - heaterWindowStart) < (uint32_t)(heaterDuty * HEATER_WINDOW_MS);
  if (liquidC >= setpointC + 2.0f) on = false;   // hard software ceiling just above setpoint
  if (on != heaterPinOn) heaterPin(on);
}

void serviceVacuum() {
  if (isnan(chamberKpa)) { relaySet(PCF_R2_VACUUM, false); vacuumPumpOn = false; return; }
  if (!vacuumPumpOn && chamberKpa > VAC_ON_ABOVE_KPA)  { vacuumPumpOn = true;  relaySet(PCF_R2_VACUUM, true); }
  if (vacuumPumpOn  && chamberKpa < VAC_OFF_BELOW_KPA) { vacuumPumpOn = false; relaySet(PCF_R2_VACUUM, false); }
}

void beep(uint8_t count) {
  for (uint8_t i = 0; i < count; i++) { buzzer(true); delay(120); buzzer(false); delay(120); }
}

void beginCycle() {
  if (!lidClosed) { Serial.println("{\"event\":\"refused\",\"reason\":\"lid open\"}"); return; }
  if (!podReady)  { Serial.println("{\"event\":\"refused\",\"reason\":\"no pod read\"}"); return; }
  if (!waterPresent) { Serial.println("{\"event\":\"refused\",\"reason\":\"water tank empty\"}"); return; }
  if (isnan(liquidC) || !scaleOk) { Serial.println("{\"event\":\"refused\",\"reason\":\"sensors not ready\"}"); return; }
  cycleStart = millis();
  evaporatedG = 0.0f;
  relaySet(PCF_R6_LIDLOCK, true);         // lock the lid
  massBase = massG;
  relaySet(PCF_R5_INLET, true);           // open the inlet valve
  setState(S_FILL);
}

void runStateMachine() {
  uint32_t inState = millis() - stateSince;

  switch (state) {
    case S_IDLE:
      break;

    case S_READY:
      if (!podReady) { setState(S_IDLE); break; }
      if (startRequested || (AUTO_START && lidClosed)) { startRequested = false; beginCycle(); }
      break;

    case S_FILL: {
      float added = massG - massBase;
      if (added >= profile.waterMl) {
        relaySet(PCF_R5_INLET, false);
        setState(S_SOAK);
      } else if (inState > MAX_FILL_MS) {
        fault("water fill timeout");
      }
      break;
    }

    case S_SOAK:
      // Gentle warm-up while the herb hydrates: hold well below the boil setpoint.
      serviceHeater(min(profile.setpointC - 20.0f, 60.0f));
      if (inState >= (uint32_t)profile.presoakS * 1000UL) {
        heaterPid.reset();
        massAtBoilStart = massG;
        relaySet(PCF_R3_RECIRC, true);
        relaySet(PCF_R7_EXHAUST, true);
        setState(S_BOIL);
      }
      break;

    case S_BOIL:
      serviceHeater(profile.setpointC);
      serviceVacuum();
      evaporatedG = massAtBoilStart - massG;
      if (evaporatedG >= profile.targetEvapG - EVAP_TOL_G) {
        heaterOff();
        relaySet(PCF_R2_VACUUM, false); vacuumPumpOn = false;
        relaySet(PCF_R3_RECIRC, false);
        relaySet(PCF_R7_EXHAUST, false);
        setState(S_VENT);
      } else if (inState > MAX_BOIL_MS) {
        fault("boil did not reach the target reduction in time");
      }
      break;

    case S_VENT:
      // No vent valve is fitted: the chamber is expected to bleed back to ambient.
      if ((!isnan(chamberKpa) && chamberKpa >= VENT_DONE_KPA) || isnan(chamberKpa)) {
        massBeforeDispense = massG;
        relaySet(PCF_R4_DISPENSE, true);
        setState(S_DISPENSE);
      } else if (inState > MAX_VENT_MS) {
        fault("chamber failed to vent");
      }
      break;

    case S_DISPENSE: {
      float delivered = massBeforeDispense - massG;
      if (delivered >= profile.doseMl) {
        relaySet(PCF_R4_DISPENSE, false);
        if (profile.tdsMinPpm > 0 && tdsPpm < profile.tdsMinPpm)
          Serial.printf("{\"event\":\"warning\",\"reason\":\"TDS below profile minimum\",\"tds_ppm\":%.0f}\n", tdsPpm);
        setState(S_EJECT);
      } else if (inState > MAX_DISPENSE_MS) {
        relaySet(PCF_R4_DISPENSE, false);
        fault("dispense timeout");
      }
      break;
    }

    case S_EJECT:
      relaySet(PCF_R6_LIDLOCK, false);       // unlock
      ejector.write(90);                      // trip the pod catch
      delay(600);
      ejector.write(0);
      podReady = false;
      beep(3);
      setState(S_DONE);
      break;

    case S_DONE:
      if (!lidClosed || inState > 15000UL) setState(S_IDLE);   // ready for the next pod
      break;

    case S_FAULT:
      break;   // outputs already off; wait for 'r'
  }
}

// ------------------------------------------------------------------ UI
void drawDisplay() {
  if (!oledOk) return;
  oled.clearDisplay();
  oled.setTextSize(1);
  oled.setTextColor(SSD1306_WHITE);
  oled.setCursor(0, 0);
  oled.printf("iKwath  %s", STATE_NAMES[state]);
  oled.setCursor(0, 12);
  if (isnan(liquidC)) oled.print("Temp  --"); else oled.printf("Temp  %.1f C", liquidC);
  oled.setCursor(0, 22);
  if (isnan(chamberKpa)) oled.print("Press --"); else oled.printf("Press %.1f kPa", chamberKpa);
  oled.setCursor(0, 32);
  oled.printf("Mass  %.0f g", isnan(massG) ? 0.0f : massG);
  oled.setCursor(0, 42);
  oled.printf("Evap  %.0f/%.0f g", evaporatedG, profile.targetEvapG);
  oled.setCursor(0, 54);
  if (state == S_FAULT) oled.print(faultReason.substring(0, 21));
  else oled.printf("%s heater %d%%", podReady ? (profile.fromTag ? "Pod" : "Dflt") : "No pod", (int)(heaterDuty * 100));
  oled.display();
}

void updateLeds() {
  ledSet(LED_RED,   state == S_FAULT);
  ledSet(LED_AMBER, state == S_FILL || state == S_SOAK || state == S_BOIL || state == S_VENT);
  ledSet(LED_GREEN, state == S_READY || state == S_DONE);
  ledSet(LED_BLUE,  state == S_DISPENSE || state == S_EJECT);
  ledsShow();
}

void printTelemetry() {
  Serial.printf("{\"state\":\"%s\",\"liquid_c\":%.2f,\"chamber_kpa\":%.1f,\"mass_g\":%.1f,\"evap_g\":%.1f,"
                "\"target_evap_g\":%.0f,\"tds_ppm\":%.0f,\"heater_pct\":%d,\"vacuum\":%s,\"lid\":%s,\"fault\":\"%s\"}\n",
                STATE_NAMES[state], isnan(liquidC) ? -1.0f : liquidC, isnan(chamberKpa) ? -1.0f : chamberKpa,
                isnan(massG) ? 0.0f : massG, evaporatedG, profile.targetEvapG, tdsPpm,
                (int)(heaterDuty * 100), vacuumPumpOn ? "true" : "false", lidClosed ? "true" : "false",
                faultReason.c_str());
}

void abortCycle() {
  allOutputsOff();
  faultReason = "";
  podReady = false;
  setState(S_IDLE);
}

void handleCommand(String line) {
  line.trim();
  if (line.length() == 0) return;
  if (line == "s") { startRequested = true; if (state == S_READY) { startRequested = false; beginCycle(); } }
  else if (line == "x") { abortCycle(); }
  else if (line == "r") {
    if (state == S_FAULT && !boilOver && (isnan(liquidC) || liquidC < LIQUID_TRIP_C - 3.0f)) {
      faultReason = ""; podReady = false; setState(S_IDLE);
    } else Serial.println("{\"event\":\"refused\",\"reason\":\"fault cause still present\"}");
  }
  else if (line == "t") { Serial.println(tareScale() ? "{\"event\":\"tared\"}" : "{\"event\":\"tare_failed\"}"); }
  else if (line.startsWith("cal ")) {
    float grams = line.substring(4).toFloat();
    double avg;
    if (grams > 0 && scale.readAverage(15, avg) && fabs(avg - tareRaw) > 100) {
      countsPerG = (float)((avg - tareRaw) / grams);
      prefs.putFloat("cpg", countsPerG);
      Serial.printf("{\"event\":\"calibrated\",\"counts_per_g\":%.3f}\n", countsPerG);
    } else Serial.println("{\"event\":\"calibration_failed\"}");
  }
  else Serial.println("commands: s start | x abort | r reset fault | t tare | cal <grams>");
}

void pollSerial() {
  static String buf;
  while (Serial.available()) {
    char c = (char)Serial.read();
    if (c == '\n' || c == '\r') { handleCommand(buf); buf = ""; }
    else if (buf.length() < 40) buf += c;
  }
}

#if ENABLE_WIFI
void sendStatus() {
  server.sendHeader("Access-Control-Allow-Origin", "*");
  String json = String("{\"state\":\"") + STATE_NAMES[state] + "\",\"liquid_c\":" + String(isnan(liquidC) ? -1 : liquidC, 2) +
                ",\"chamber_kpa\":" + String(isnan(chamberKpa) ? -1 : chamberKpa, 1) +
                ",\"evap_g\":" + String(evaporatedG, 1) + ",\"target_evap_g\":" + String(profile.targetEvapG, 0) +
                ",\"tds_ppm\":" + String(tdsPpm, 0) + ",\"fault\":\"" + faultReason + "\"}";
  server.send(200, "application/json", json);
}
void startWeb() {
  WiFi.mode(WIFI_STA);
  WiFi.begin(WIFI_SSID, WIFI_PASSWORD);
  server.on("/status", sendStatus);
  server.on("/start", []() { handleCommand("s"); sendStatus(); });
  server.on("/stop",  []() { handleCommand("x"); sendStatus(); });
  server.begin();
}
#endif

// ------------------------------------------------------------------ setup / loop
void setup() {
  Serial.begin(SERIAL_BAUD);

  // Make every output safe before anything else initialises.
  pinMode(PIN_HEATER, OUTPUT);
  heaterPin(false);
  pinMode(PIN_LID, INPUT);         // external 10k pull-ups on the board
  pinMode(PIN_BOILOVER, INPUT);
  pinMode(PIN_LEVEL, INPUT);
  analogReadResolution(12);

  Wire.begin(PIN_I2C_SDA, PIN_I2C_SCL);
  pcfRelays = RELAY_ACTIVE_LOW ? 0xFF : 0x00;
  pcfRelays &= ~(1 << PCF_BUZZER);
  pcfWrite(ADDR_PCF_RELAYS, pcfRelays);
  pcfLeds = LED_ACTIVE_LOW ? 0xFF : 0x00;
  pcfWrite(ADDR_PCF_LEDS, pcfLeds);

  oledOk = oled.begin(SSD1306_SWITCHCAPVCC, ADDR_OLED);
  bmpOk  = bmp.begin(ADDR_BMP280);
  if (bmpOk) bmp.setSampling(Adafruit_BMP280::MODE_NORMAL, Adafruit_BMP280::SAMPLING_X1,
                             Adafruit_BMP280::SAMPLING_X4, Adafruit_BMP280::FILTER_X4, Adafruit_BMP280::STANDBY_MS_63);

  liquidProbe.begin();
  liquidProbe.setWaitForConversion(true);

  SPI.begin(PIN_NFC_SCK, PIN_NFC_MISO, PIN_NFC_MOSI, PIN_NFC_SS);
  nfc.PCD_Init();

  ejector.setPeriodHertz(50);
  ejector.attach(PIN_SERVO, 500, 2400);
  ejector.write(0);

  scale.begin();
  prefs.begin("ikwath", false);
  countsPerG = prefs.getFloat("cpg", HX711_COUNTS_PER_G);
  tareScale();

#if ENABLE_WIFI
  startWeb();
#endif

  Serial.printf("{\"event\":\"boot\",\"oled\":%s,\"bmp280\":%s,\"counts_per_g\":%.2f}\n",
                oledOk ? "true" : "false", bmpOk ? "true" : "false", countsPerG);
  setState(S_IDLE);
}

void loop() {
  uint32_t now = millis();

  pollSerial();
  pollPod();

  if (now - lastSensor >= SENSOR_MS) {
    lastSensor = now;
    readSensors();
    safetyCheck();
  }

  runStateMachine();

  if (now - lastDisplay >= DISPLAY_MS) { lastDisplay = now; drawDisplay(); updateLeds(); }
  if (now - lastTelemetry >= TELEMETRY_MS) { lastTelemetry = now; printTelemetry(); }

#if ENABLE_WIFI
  server.handleClient();
#endif
}

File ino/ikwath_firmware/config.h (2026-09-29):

#pragma once
// Tunable settings. Values marked CALIBRATE must be measured on the real build.

// ---- Behaviour switches ----
#define AUTO_START           0     // 1: start as soon as a valid pod is read and the lid is latched
#define ENABLE_WIFI          0     // 1: serve /status /start /stop over HTTP (fill in credentials)
#define RELAY_ACTIVE_LOW     1     // most opto relay modules switch on a LOW input
#define LED_ACTIVE_LOW       0     // LEDs on the expander: 0 = high turns on
#define SERIAL_BAUD          115200

// ---- WiFi (only used when ENABLE_WIFI = 1). Never commit real credentials. ----
#define WIFI_SSID            "your_wifi_name"
#define WIFI_PASSWORD        "your_wifi_password"

// ---- Default brew profile (used when the pod tag has no valid payload) ----
#define DEF_WATER_ML         400
#define DEF_PRESOAK_S        180
#define DEF_TARGET_EVAP_G    300.0f     // 4:1 reduction of 400 g
#define DEF_SETPOINT_C       86.0f
#define DEF_DOSE_ML          100
#define DEF_TDS_MIN_PPM      0          // 0 disables the concentration check

// ---- Process limits ----
#define BAND_LOW_C           85.0f
#define BAND_HIGH_C          90.0f
#define VAC_ON_ABOVE_KPA     58.0f      // pump on above this absolute pressure
#define VAC_OFF_BELOW_KPA    52.0f      // pump off below this
#define VENT_DONE_KPA        95.0f      // treat chamber as vented above this
#define EVAP_TOL_G           2.0f
#define HEATER_WINDOW_MS     2000       // time-proportional window (protects the relay)

// ---- Safety trips (firmware layer; hardware cutoffs are separate) ----
#define LIQUID_TRIP_C        92.0f
#define ENCLOSURE_TRIP_C     60.0f
#define MAX_FILL_MS          90000UL
#define MAX_BOIL_MS          (25UL * 60UL * 1000UL)
#define MAX_VENT_MS          30000UL
#define MAX_DISPENSE_MS      45000UL

// ---- PID for the heater (starting values, tune on the rig) ----
#define PID_KP               0.35f
#define PID_KI               0.02f
#define PID_KD               0.6f

// ---- Load cell ----
// CALIBRATE: counts per gram. The 'cal <grams>' serial command measures and stores it.
#define HX711_COUNTS_PER_G   420.0f

// ---- NTC (10k, beta 3950, 10k to 3V3, NTC to ground) ----
#define NTC_R_FIXED          10000.0f
#define NTC_R25              10000.0f
#define NTC_BETA             3950.0f

// ---- Timing ----
#define TELEMETRY_MS         1000
#define DISPLAY_MS           250
#define SENSOR_MS            250

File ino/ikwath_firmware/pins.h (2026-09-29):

#pragma once
// iKwath control board: ESP32 DevKit V1 (38 pin). Matches docs/pinout-and-buses.md.

// 1-Wire liquid temperature probe (DS18B20, 4.7k pull-up to 3.3V)
#define PIN_DS18B20      4

// HX711 load-cell amplifier
#define PIN_HX711_DT     16
#define PIN_HX711_SCK    17

// MFRC522 NFC reader (SPI)
#define PIN_NFC_SS       5
#define PIN_NFC_SCK      18
#define PIN_NFC_MISO     19
#define PIN_NFC_MOSI     23
#define PIN_NFC_RST      27

// Shared I2C bus (4.7k pull-ups)
#define PIN_I2C_SDA      21
#define PIN_I2C_SCL      22

// Analog inputs
#define PIN_TDS          34   // TDS probe (input-only pin)
#define PIN_NTC          32   // enclosure NTC divider

// Digital safety inputs (10k pull-up + 100nF debounce on the board)
#define PIN_LID          25
#define PIN_BOILOVER     26
#define PIN_LEVEL        33

// Outputs
#define PIN_SERVO        13   // SG90 pod ejector
#define PIN_HEATER       14   // Relay 1: heater, time-proportional PID

// I2C addresses
#define ADDR_OLED        0x3C
#define ADDR_BMP280      0x76
#define ADDR_PCF_RELAYS  0x20 // Relay 2..7 and buzzer
#define ADDR_PCF_LEDS    0x21 // status LEDs

// PCF8574 #1 bit assignment
#define PCF_R2_VACUUM    0
#define PCF_R3_RECIRC    1
#define PCF_R4_DISPENSE  2
#define PCF_R5_INLET     3
#define PCF_R6_LIDLOCK   4
#define PCF_R7_EXHAUST   5
#define PCF_BUZZER       6

// PCF8574 #2 bit assignment
#define LED_RED          0
#define LED_AMBER        1
#define LED_GREEN        2
#define LED_BLUE         3

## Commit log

2026-09-21 Add final KiCad PCB design files and schematics for iKwath
    [ikwath.kicad_pcb, ikwath.kicad_sch]
2026-09-29 v0.4.0: add ESP32 firmware draft, docs set, INSTALL, CHANGELOG, PUSH_LOG, project report; correct README status claims
    [config.h, ikwath_firmware.ino, pins.h]
